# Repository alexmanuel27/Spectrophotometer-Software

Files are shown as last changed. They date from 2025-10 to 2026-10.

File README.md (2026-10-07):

# System A – AS7265x multispectral spectrophotometer

Firmware and control software for **System A** of the article

> A. M. Rivera-Rivera, D. Martinez-Ortiz, F. Quitin, D. Terwagne, S. C. Nicolis, E. Altshuler, A. Campo,
> *Low-Cost Spectrophotometers: A Comparative Evaluation of Open-Source Architectures* (2026), arXiv:XXXX.XXXXX.

System A is a low-cost, portable absorbance/transmittance spectrophotometer built around the
SparkFun Triad AS7265x sensor (18 discrete channels, 410–940 nm, ~20 nm FWHM) and an ESP32
microcontroller. A 10 W halogen lamp transmits light through a standard 10 mm cuvette onto the
sensor; a Python program on the host computer switches the lamp, acquires the spectra, and
computes absorbance and transmittance.

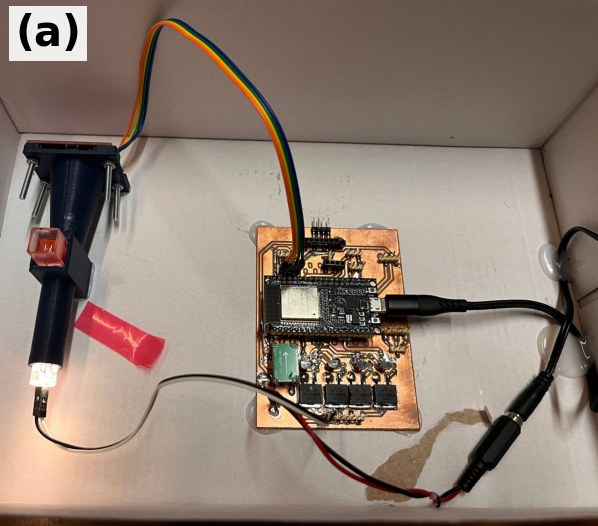
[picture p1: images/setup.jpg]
System A


*System A: AS7265x sensor in a 3D-printed structure, controlled by an ESP32 (Fig. 1a of the article).*

---

## Repository layout

```
firmware/Spectro18_V1/   Arduino sketch for the ESP32
software/                Host acquisition program (Python, GUI)
hardware/                3D-printable parts and wiring diagram
images/                  Pictures used in this README
.github/workflows/       CI that builds standalone executables (PyInstaller)
```

---

## Bill of materials

Costs as reported in Table IV of the article (EUR, approximate).

| Component | Description | Photo | Cost (€) |
|---|---|---|---:|
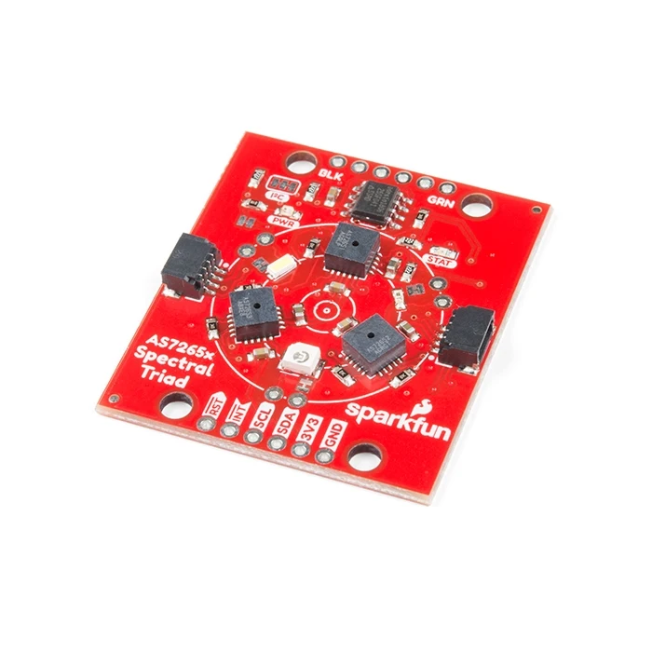
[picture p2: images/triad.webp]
Triad
| **SparkFun Triad AS7265x** | 18-channel spectral sensor (410–940 nm), Qwiic/I²C. [SparkFun](https://www.sparkfun.com/sparkfun-triad-spectroscopy-sensor-as7265x-qwiic.html) |  | 65.00 |
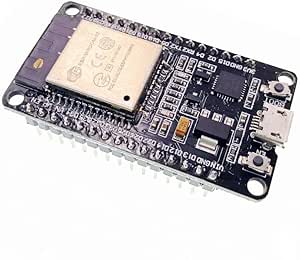
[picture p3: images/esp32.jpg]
ESP32
| **ESP32 development board** | Microcontroller; talks to the sensor over I²C and to the PC over USB serial. |  | 8.00 |
| **3D-printed enclosure + accessories** | Sensor/lamp/cuvette alignment structure ([`hardware/system-a-enclosure.stl`](hardware/system-a-enclosure.stl)). | | 10.00 |
| **Wiring, PCB, power supply** | Jumper wires, lamp switch, USB cable, supply. | | 5.00 |
| | | **Total** | **88.00** |

Not included in the total (as in the article):

| Item | Notes |
|---|---|
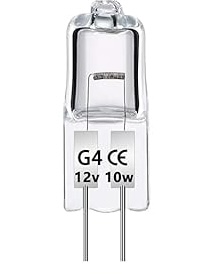
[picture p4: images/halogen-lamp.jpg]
Halogen lamp
| **10 W halogen lamp** | Light source used for all measurements in the article. Switched by the ESP32 (GPIO 32) through a relay module.  |
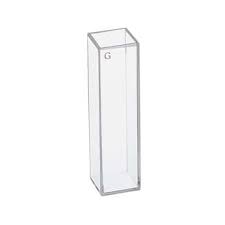
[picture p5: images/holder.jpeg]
Cuvette
| **10 mm optical cuvettes** | Standard plastic cuvettes.  |
| Host computer | Windows, macOS or Linux, with a free USB port. |

---

## Wiring

| ESP32 pin | Connected to | Notes |
|---|---|---|
| 3V3 | AS7265x 3.3V | Qwiic red wire |
| GND | AS7265x GND, relay module GND | Common ground |
| GPIO 21 (SDA) | AS7265x SDA | Default ESP32 I²C bus |
| GPIO 22 (SCL) | AS7265x SCL | Default ESP32 I²C bus |
| GPIO 32 | Relay module input (switches the halogen lamp) | **Active-low**: `LOW` = lamp on, `HIGH` = lamp off |

The on-board LEDs of the AS7265x are not used; only the external halogen lamp illuminates the sample.
Place the lamp, the cuvette and the sensor on one optical axis inside the enclosure and keep the
whole set-up in darkness during measurements.

---

## Installation

### 1. Firmware (ESP32)

1. Install the [Arduino IDE](https://www.arduino.cc/en/software) (2.x) and the **esp32** board package by Espressif.
2. Install the **SparkFun AS7265X Arduino Library** from the Library Manager.
3. Open `firmware/Spectro18_V1/Spectro18_V1.ino`, select your ESP32 board and port, and upload.
4. Open the Serial Monitor at **115200 baud**: the board prints `LISTO` and then one line of
   18 comma-separated calibrated channel readings (µW/cm²) per measurement, ordered by wavelength.

Serial commands accepted by the firmware:

| Command | Effect | Reply |
|---|---|---|
| `LIGHT_ON`  | Switches the lamp on  | `LUZ_ENCENDIDA` |
| `LIGHT_OFF` | Switches the lamp off | `LUZ_APAGADA` |

### 2. Host software

**Option A – standalone executable.** Download the build for your OS from the repository
*Releases* page (built automatically by `.github/workflows/build.yml` for every `v*.*.*` tag).
Install the USB-serial driver of your ESP32 board (CP210x or CH340) if the port does not appear.

**Option B – from source** (Python 3.10–3.12):

```bash
git clone https://gitlab.com/fablab-ulb/projects/cuban-water-lab/spectrophotometer-software.git
cd spectrophotometer-software
python -m venv env && source env/bin/activate      # Windows: env\Scripts\activate
pip install -r requirements.txt
python software/spectrophotometer.py
```

---

## Usage

1. Connect the ESP32 by USB and start the program. Select the serial port in the dialog.
2. **Take Reference.** Insert a cuvette with the blank (solvent, e.g. distilled water) and click
   *Take Reference*. The lamp is switched on, allowed to stabilise for 5 s, ten valid readings are
   averaged (I₀), and the lamp is switched off.
3. **Measure Sample.** Replace the blank with the sample and click *Measure Sample*. Ten readings
   are averaged (I) and the program plots, for the 18 channels,
   - absorbance A = log₁₀(I₀ / I)
   - transmittance T = 100 · I / I₀ (%)
4. **Save.** Click *Save* and enter a sample name to write a CSV and a PNG.
5. **Measure Error** (optional). Takes ten consecutive readings of the sample in the cuvette and saves
   every individual absorbance spectrum plus their mean and standard deviation, to assess repeatability.

If a file named `calibration_factor.npy` (18 multiplicative factors, one per channel) is present in
the working directory, the absorbance is multiplied by it; otherwise a factor of 1 is used.

### Output files

Files are written to `~/Descargas/Spectra_Absorbance_CSV/` and `~/Descargas/Spectra_Absorbance_PNG/`
(the folder name is set in `software/spectrophotometer.py`).

`<name>_<YYYYMMDD_HHMMSS>.csv` (one row per channel):

| Column | Unit | Meaning |
|---|---|---|
| `Wavelength_nm` | nm | Channel centre wavelength |
| `I0_Reference_uW_per_cm2` | µW/cm² | Mean reference (blank) reading |
| `I_Sample_uW_per_cm2` | µW/cm² | Mean sample reading |
| `Absorbance_Calibrated` | AU | log₁₀(I₀/I) × correction factor (factor = 1 if none is loaded) |
| `Transmittance_%` | % | 100 · I/I₀ |

`error_measurement_<YYYYMMDD_HHMMSS>.csv`: `Wavelength_nm`, `I0_Reference_uW_per_cm2`,
`Absorbance_Reading_1` … `Absorbance_Reading_10`, `Absorbance_Mean`, `Absorbance_Std`.

---

## How to cite

If you use this design or software, please cite the article above. Citation metadata is provided in
[`CITATION.cff`](CITATION.cff).

## Licence

Released under the [MIT License](LICENSE).

## Acknowledgements

Developed within the project *“In situ monitoring of water quality in Cuban bays: creating and
promoting the use of a scientific toolbox”*, supported by ARES with funding from the Belgian
Development Cooperation, at the Innovation Laboratory (CUJAE, Havana) and Fab Lab ULB (Université
libre de Bruxelles). A. C. and S. C. N. acknowledge funding from the European Union's Horizon Europe
research and innovation programme under grant agreement No. 101181363 (BioDiMoBot).
We thank Axel Cornu for valuable advice.

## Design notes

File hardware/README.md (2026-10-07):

# Hardware

Mechanical and electrical design files for System A.

| File | Content |
|---|---|
| `system-a-enclosure.stl` | 3D-printable structure holding the AS7265x sensor, the 10 mm cuvette and the lamp on one optical axis (overall size ≈ 48 × 109 × 53 mm) |

Wiring is described in the main [README](../README.md#wiring).

All files in this folder are released under the MIT licence of the repository.

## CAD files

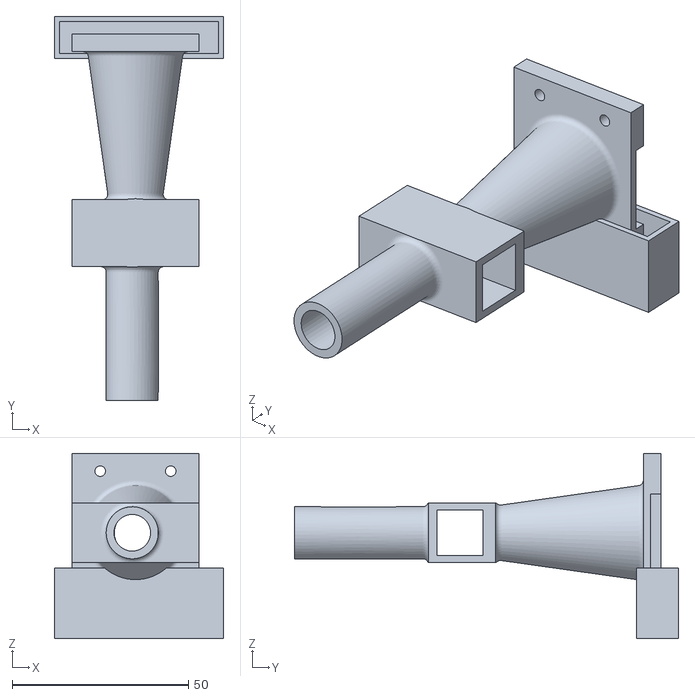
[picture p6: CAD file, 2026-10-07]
hardware/system-a-enclosure.stl
48.0 x 109.0 x 52.5

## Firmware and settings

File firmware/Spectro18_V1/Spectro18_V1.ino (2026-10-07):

#include "SparkFun_AS7265X.h"
AS7265X sensor;
const int ledPin = 32;

void setup() {
  pinMode(ledPin, OUTPUT);
  digitalWrite(ledPin, HIGH); // Lamp OFF (active-low output)
  Serial.begin(115200);

  if (sensor.begin() == false) {
    Serial.println("Sensor not detected.");
    while (1);
  }

  Serial.println("LISTO");
}

void loop() {
    if (Serial.available()) {
    String comando = Serial.readStringUntil('\n');
    comando.trim();

    if (comando == "LIGHT_ON") {
      digitalWrite(ledPin, LOW);
      delay(100);
      Serial.println("LUZ_ENCENDIDA");
      return; // Return immediately, without measuring
    }
    if (comando == "LIGHT_OFF") {
      digitalWrite(ledPin, HIGH);
      delay(100);
      Serial.println("LUZ_APAGADA");
      return;
    }
  }


  sensor.takeMeasurements();
  // Print the 18 calibrated channel values, sorted by wavelength (410-940 nm)
  Serial.print(sensor.getCalibratedA());
  Serial.print(",");
  Serial.print(sensor.getCalibratedB());
  Serial.print(",");
  Serial.print(sensor.getCalibratedC());
  Serial.print(",");
  Serial.print(sensor.getCalibratedD());
  Serial.print(",");
  Serial.print(sensor.getCalibratedE());
  Serial.print(",");
  Serial.print(sensor.getCalibratedF());
  Serial.print(",");

  Serial.print(sensor.getCalibratedG());
  Serial.print(",");
  Serial.print(sensor.getCalibratedH());
  Serial.print(",");
  Serial.print(sensor.getCalibratedR());
  Serial.print(",");
  Serial.print(sensor.getCalibratedI());
  Serial.print(",");
  Serial.print(sensor.getCalibratedS());
  Serial.print(",");
  Serial.print(sensor.getCalibratedJ());
  Serial.print(",");

  Serial.print(sensor.getCalibratedT());
  Serial.print(",");
  Serial.print(sensor.getCalibratedU());
  Serial.print(",");
  Serial.print(sensor.getCalibratedV());
  Serial.print(",");
  Serial.print(sensor.getCalibratedW());
  Serial.print(",");
  Serial.print(sensor.getCalibratedK());
  Serial.print(",");
  Serial.print(sensor.getCalibratedL());
  Serial.println();
}

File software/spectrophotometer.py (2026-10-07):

import serial
import serial.tools.list_ports
import matplotlib.pyplot as plt
import numpy as np
import csv
from datetime import datetime
import os
import tkinter as tk
from tkinter import ttk, simpledialog, messagebox
from matplotlib.widgets import Button

# === LOAD OPTIONAL CORRECTION FACTOR (if present) ===
CALIBRATION_FILE = "calibration_factor.npy"
if os.path.exists(CALIBRATION_FILE):
    CORRECTION_FACTOR = np.load(CALIBRATION_FILE)
    print(f"✅ Correction factor loaded from {CALIBRATION_FILE}")
else:
    CORRECTION_FACTOR = np.ones(18)
    print("⚠️  No calibration file found. Using factor = 1 (no correction).")

# === READING VALIDATION ===
def lectura_es_valida(valores):
    """
    Validate one sensor reading.
    Rejects it if channel D (485 nm, index 3) is zero or negative.
    """
    if valores is None:
        return False
    if len(valores) != 18:
        return False
    return valores[3] > 0  # Channel D (485 nm) must be > 0

# === SERIAL PORT SELECTION (Tkinter) ===
def select_port_gui():
    root = tk.Tk()
    root.withdraw()

    top = tk.Toplevel(root)
    top.title("Select Serial Port")
    top.geometry("400x250")

    label = ttk.Label(top, text="Choose the sensor port:", font=("Helvetica", 12))
    label.pack(pady=10)

    def list_ports():
        ports = []
        for p in serial.tools.list_ports.comports():
            if p.device:
                ports.append(p.device)
        if not ports:
            ports = ['/dev/ttyUSB0', '/dev/ttyACM0']
            if os.name == 'nt':
                ports = ['COM1', 'COM2', 'COM3', 'COM4', 'COM5']
        return ports

    available_ports = list_ports()
    selected_port = tk.StringVar(value=available_ports[0] if available_ports else "/dev/ttyUSB0")

    combo = ttk.Combobox(top, textvariable=selected_port, values=available_ports, state="readonly", width=30, font=("Helvetica", 11))
    combo.pack(pady=10)

    port = None

    def accept():
        nonlocal port
        port = selected_port.get()
        top.destroy()

    btn_frame = ttk.Frame(top)
    btn_frame.pack(pady=10)
    ttk.Button(btn_frame, text="Cancel", command=top.destroy).pack(side=tk.LEFT, padx=5)
    ttk.Button(btn_frame, text="OK", command=accept).pack(side=tk.LEFT, padx=5)

    top.grab_set()
    top.focus_set()
    top.wait_window()
    root.destroy()
    return port

# === RUN PORT SELECTION ===
try:
    port = select_port_gui()
    if not port:
        print("❌ No port selected.")
        exit(1)
except Exception as e:
    print(f"❌ Error: {e}")
    exit(1)

baud_rate = 115200
timeout = 2

# === OUTPUT FOLDERS ===
base_folder = os.path.expanduser("~/Descargas")
csv_folder = os.path.join(base_folder, "Spectra_Absorbance_CSV")
png_folder = os.path.join(base_folder, "Spectra_Absorbance_PNG")

os.makedirs(csv_folder, exist_ok=True)
os.makedirs(png_folder, exist_ok=True)

# === AS7265x CHANNEL CENTRE WAVELENGTHS (nm) ===
wavelengths = [
    410, 435, 460, 485, 510, 535,
    560, 585, 610, 645, 680, 705,
    730, 760, 810, 860, 900, 940
]

# === SERIAL CONNECTION ===
try:
    ser = serial.Serial(port, baud_rate, timeout=timeout)
    print(f"🔌 Connected to {port} at {baud_rate} bps")
except Exception as e:
    print(f"❌ Error opening serial port: {e}")
    exit(1)

# === APPLICATION STATE ===
reference = None
sample_intensity = None
absorbance_values = None
absorbance_std = None
transmittance_percent = None
count = 0

# === HELPERS ===
def clear_buffer():
    while ser.in_waiting > 0:
        ser.readline()
    plt.pause(0.1)

def wait_for_confirmation(expected_text, timeout=5):
    start_time = datetime.now()
    while (datetime.now() - start_time).seconds < timeout:
        if ser.in_waiting > 0:
            try:
                line = ser.readline().decode('utf-8', errors='ignore').strip()
                if expected_text in line:
                    return True
                if line.count(',') == 17:
                    continue
            except:
                continue
        plt.pause(0.1)
    return False

def turn_on_light():
    clear_buffer()
    ser.write(b'LIGHT_ON\n')
    success = wait_for_confirmation("LUZ_ENCENDIDA", timeout=5)
    if not success:
        print("❌ Timeout waiting for 'LUZ_ENCENDIDA'")
    return success

def turn_off_light():
    ser.write(b'LIGHT_OFF\n')
    success = wait_for_confirmation("LUZ_APAGADA", timeout=5)
    if not success:
        print("⚠️ Timeout waiting for 'LUZ_APAGADA'")
    return success

def read_spectrum():
    for _ in range(5):
        if ser.in_waiting > 0:
            line = ser.readline().decode('utf-8', errors='ignore').strip()
            parts = [x.strip() for x in line.split(',') if x.strip()]
            if len(parts) == 18 and 'A,B,C' not in line and ',' in line:
                try:
                    values = list(map(float, parts))
                    if len(values) == 18:
                        return np.array(values)
                except:
                    continue
        plt.pause(0.1)
    return None

# === DUAL PLOT SETUP ===
plt.ion()
fig, (ax_abs, ax_T) = plt.subplots(2, 1, figsize=(12, 8), gridspec_kw={'height_ratios': [1, 1]})

line_abs, = ax_abs.plot(wavelengths, [0]*18, 'o-', color='purple', linewidth=2, markersize=6, zorder=5)
errorbars = ax_abs.errorbar(wavelengths, [0]*18, yerr=[0]*18, fmt='none', ecolor='red', capsize=3, capthick=1, elinewidth=1, zorder=4)
ax_abs.set_ylabel('Absorbance (a.u.)')
ax_abs.set_title('Absorbance')
ax_abs.grid(True, alpha=0.3)
ax_abs.set_xlim(400, 960)
ax_abs.set_ylim(-0.1, 2.0)

line_T, = ax_T.plot(wavelengths, [0]*18, 's-', color='green', linewidth=2, markersize=5)
ax_T.set_xlabel('Wavelength (nm)')
ax_T.set_ylabel('Transmittance (%)')
ax_T.set_title('Transmittance')
ax_T.grid(True, alpha=0.3)
ax_T.set_xlim(400, 960)
ax_T.set_ylim(0, 100)

fig.suptitle('🔬 Spectrophotometer - Calibrated', fontsize=14, fontweight='bold')

# === BUTTONS ===
ax_btn_ref = plt.axes([0.1, 0.02, 0.2, 0.05])
btn_ref = Button(ax_btn_ref, 'Take Reference', color='skyblue')

ax_btn_sample = plt.axes([0.35, 0.02, 0.2, 0.05])
btn_sample = Button(ax_btn_sample, 'Measure Sample', color='lightgreen')

ax_btn_save = plt.axes([0.6, 0.02, 0.2, 0.05])
btn_save = Button(ax_btn_save, 'Save', color='gold')

ax_btn_error = plt.axes([0.85, 0.02, 0.13, 0.05])
btn_error = Button(ax_btn_error, 'Measure Error', color='orange')
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

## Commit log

2025-10-28 calibration improvements
    [mi_muestra_1.csv, mi_muestra_2.csv, mi_muestra_3.csv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]
2025-12-25 samples and error
    [deep_umC_20251119_165457.csv, deep_umC_20251119_165457_calibrated.csv, grape_umC_20251116_191419.csv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]
2026-10-07 Remove files unrelated to System A (thermal-camera sketch, fluorescence variant, old test data, ad-hoc analysis scripts, duplicate release workflow)
    Claude-Session: https://claude.ai/code/session_018ENge2Jio4zRB4p7RfLqyn
    [deep_umC_20251119_165457.csv, deep_umC_20251119_165457_calibrated.csv, grape_umC_20251116_191419.csv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]
2026-10-07 Untrack reference-instrument calibration files (kept locally, now ignored)
    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
    [mi_muestra_1.csv, mi_muestra_2.csv, mi_muestra_3.csv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]
2026-10-07 Add hardware/ folder for enclosure and wiring files
    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
2026-10-07 Rewrite README: halogen-lamp setup, BOM matching Table IV, wiring, install, usage, output format, citation
    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
2026-10-07 Add System A enclosure STL
    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
    [system-a-enclosure.stl]
2026-10-07 README: halogen lamp photo, relay module, link to enclosure STL
    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
2026-10-07 README: lamp is switched through a relay module on GPIO 32
    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
